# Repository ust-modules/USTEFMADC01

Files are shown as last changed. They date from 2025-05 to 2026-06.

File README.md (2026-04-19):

# EFMADC01 - Electric Field Mill ADC Module

The **EFMADC01** module is designed to provide an **analog front-end** and **ADC conversion** for [Electric Field Mill sensor](https://github.com/UniversalScientificTechnologies/THUNDERMILL01) development and experiments. It processes analog signals from the field mill electrodes and converts them into digital data for further processing.

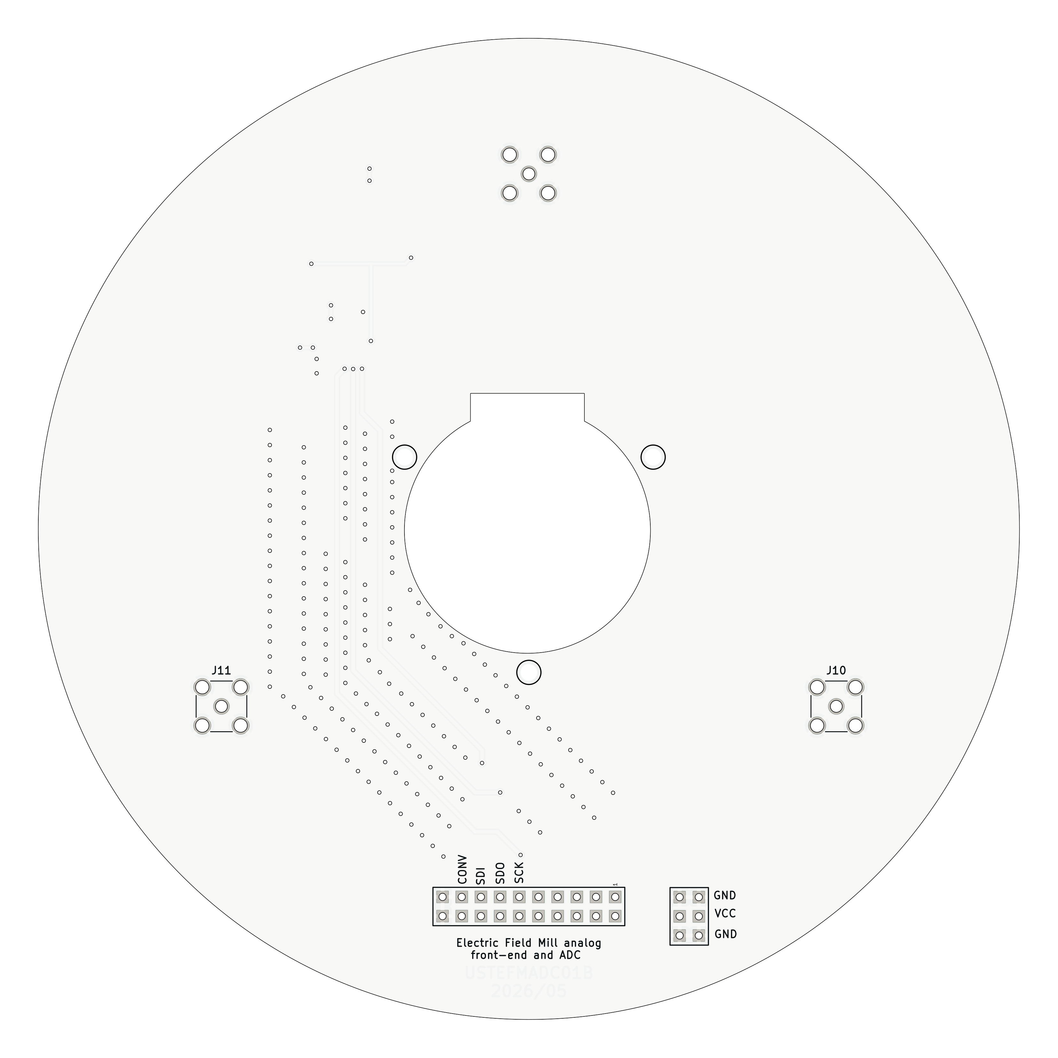
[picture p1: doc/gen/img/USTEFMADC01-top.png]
EFMADC01 top


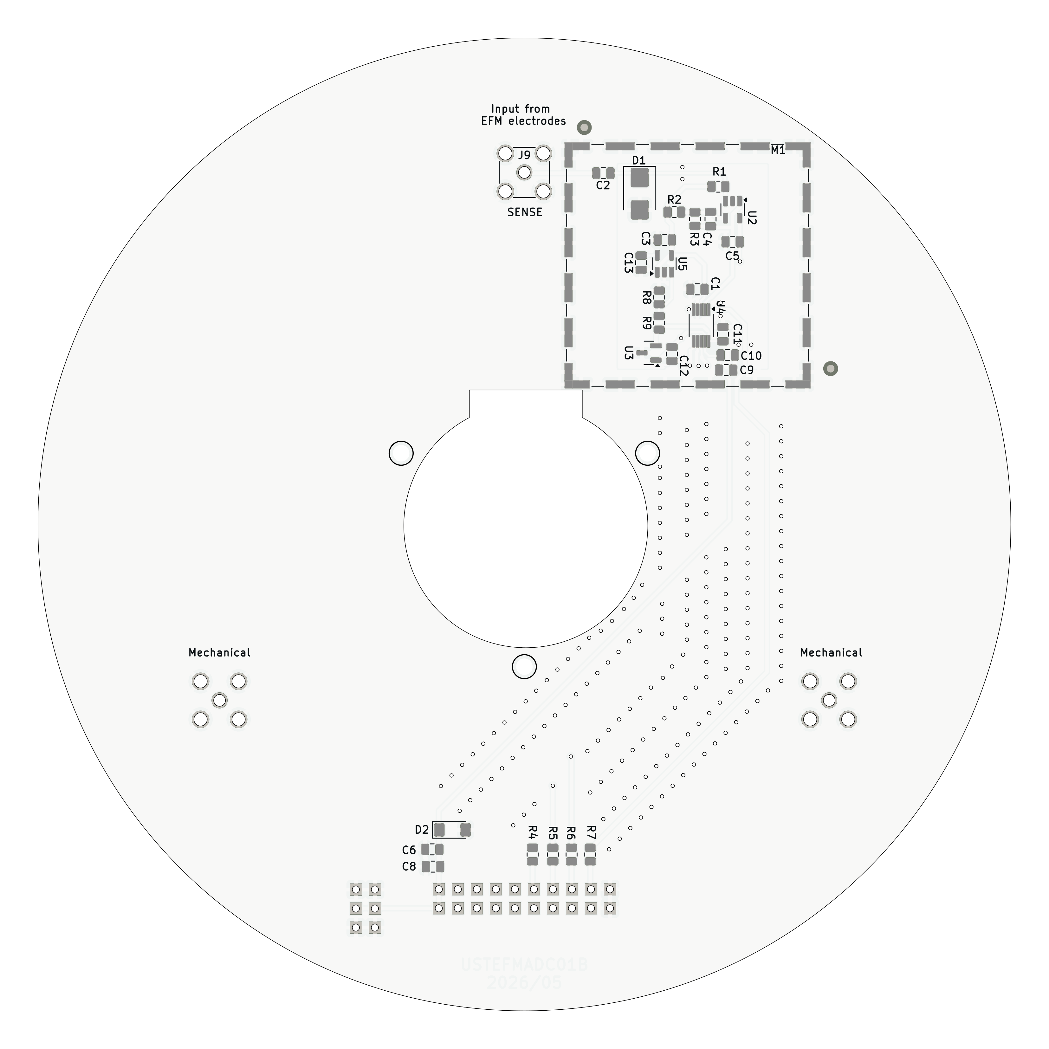
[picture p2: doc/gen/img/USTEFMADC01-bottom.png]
EFMADC01 bottom


## Features

- **High-Precision ADC**: Utilizes the **LTC1865** 16-bit, 250ksps analog-to-digital converter.
- **Low-Noise Analog Front End**: Incorporates **OPA314** operational amplifiers for signal conditioning.
- **Precision and stable Voltage Reference**: Includes a **1.25V reference** for accurate ADC operation.
- **Flexible Power Supply**: Supports **3.3V to 5V** operation.
- **RF Shielding**: Equipped with shielding to reduce external interference.
- **MCX Connector Input**: Enables high-quality signal connection.

## Functional Description

The **EFMADC01** module consists of three main blocks:

1. **Analog Front End (AFE)**:
   - Uses **OPA314** operational amplifiers for signal buffering and amplification.
   - High-impedance resistor (10MΩ) allows direct signal acquisition from the field mill sensor electrodes.

2. **ADC Conversion**:
   - **LTC1865-MS** ADC provides **16-bit resolution** with **250ksps sampling rate**.
   - Accepts differential input signals and supports SPI communication.

3. **Power and Reference**:
   - Powered by an external **3.3V or 5V** supply.
   - Features a **BZV55C-6.2V** Zener diode for overvoltage protection.
   - Uses a **1.25V precision voltage reference** for ADC stability.

## Hardware Connections

### Power Supply:
- **VCC**: Accepts **3.3V to 5V** input.
- **GNDA** and **GND**: Ground connections.

### Analog Input:
- **J9 (MCX Connector)**: Main analog signal input.
- **Operational amplifier stage** conditions the signal before ADC conversion.

## Typical Application

The **EFMADC01** module is primarily used in electric field mill experiments to measure atmospheric electric fields. It can also be employed in low-frequency scientific measurements where high-resolution ADC conversion is required.

## Schematic

For detailed circuit information, please take a look at the [EFMADC01 schematic](/doc/gen/EFMADC01-schematic.pdf) in the documentation.

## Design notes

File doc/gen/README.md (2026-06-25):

# PCB

Board size: 130.0x130.0 mm (5.12x5.12 inches)

- This is the size of the rectangle that contains the board
- Thickness: 1.6 mm (63 mils)
- Material: FR4
- Finish: Immersion gold
- Layers: 2
- Copper thickness: 35 µm

Solder mask: TOP / BOTTOM

- Color: White

Silk screen: TOP / BOTTOM

- Color: Black

Special features:

- Edge plating

Stackup:

| Name | Type | Color | Thickness [µm]| Material | Er | Loss tan |
|---|---|---|---|---|---|---|
| F.SilkS | Top Silk Screen | Black | | | | |
| F.Paste | Top Solder Paste | | | | | |
| F.Mask | Top Solder Mask | White | 10 | | | |
| F.Cu | copper | | 35 | | | |
| dielectric 1 | core | | 1510 | FR4 | 4.5 | 0.020 |
| B.Cu | copper | | 35 | | | |
| B.Mask | Bottom Solder Mask | White | 10 | | | |
| B.Paste | Bottom Solder Paste  | | | | | |
| B.SilkS | Bottom Silk Screen | Black | | | | |

# Important sizes

Clearance: 0.2 mm (8 mils)

Track width: 0.2 mm (8 mils)

- By design rules: 0.2 mm (8 mils)

Drill: 0.5 mm (20 mils)

- Vias: 0.5 mm (20 mils) [Design: 0.4 mm (16 mils)]
- Pads: 1.0 mm (39 mils)
- The above values are real drill sizes, they add 0.1 mm (4 mils) to plated holes (PTH)

Via: 0.8/0.4 mm (31/16 mils)

- By design rules: 0.4/0.3 mm (16/12 mils)
- Micro via: yes [0.2/0.1 mm (8/4 mils)]
- Buried/blind via: yes
- Total: 195 (thru: 195 buried/blind: 0 micro: 0)

Outer Annular Ring: 0.15 mm (6 mils)

- By design rules: 0.23 mm (9 mils)

Eurocircuits class: 4B
- Using min drill 0.5 mm for an OAR of 0.15 mm

# General stats

Components count: (SMD/THT)

- Top: 0/4 (THT)
- Bottom: 30/2 (SMD + THT)

Defined tracks:

- 0.2 mm (8 mils)
- 0.25 mm (10 mils)
- 0.3 mm (12 mils)
- 0.45 mm (18 mils)
- 0.5 mm (20 mils)

Used tracks:

- 0.2 mm (8 mils) (5) defined: yes
- 0.25 mm (10 mils) (24) defined: yes
- 0.3 mm (12 mils) (25) defined: yes
- 0.45 mm (18 mils) (92) defined: yes

Defined vias:

Used vias:

- 0.8/0.4 mm (31/16 mils) (Count: 195, Aspect: 2.0 A) defined: no

Holes (excluding vias):

- 0.89 mm (35 mils) (26)
- 1.5 mm (59 mils) (3)
- 1.7 mm (67 mils) (12)

Oval holes:

Drill tools (including vias and computing adjusts and rounding):

- 0.5 mm (20 mils) (195)
- 1.0 mm (39 mils) (26)
- 1.6 mm (63 mils) (3)
- 1.8 mm (71 mils) (12)

Solder paste stats:

Using a paste with 87.75 % alloy, that has an specific gravity for the alloy of 7.4 g/cm³
and 1.0 g/cm³ for the flux. This paste has an specific gravity of  4.15 g/cm³.

The stencil thickness is  0.12 mm.

| Side | Pads with paste | Area [mm²] | Paste [g] |
|---|---|---|---|
| Total  | 97 | 173.00 | 0.86 |

Note: this is just an approximation to the theoretical value. Margins of the solder mask and waste aren't computed.

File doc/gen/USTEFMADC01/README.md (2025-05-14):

# PCB

Board size: 130.0x130.0 mm (5.12x5.12 inches)

- This is the size of the rectangle that contains the board
- Thickness: 1.6 mm (63 mils)
- Material: FR4
- Finish: Immersion gold
- Layers: 2
- Copper thickness: 35 µm

Solder mask: TOP / BOTTOM

- Color: White

Silk screen: TOP / BOTTOM

- Color: Black

Special features:

- Castellated pads
- Edge plating

Stackup:

| Name | Type | Color | Thickness [µm]| Material | Er | Loss tan |
|---|---|---|---|---|---|---|
| F.SilkS | Top Silk Screen | Black | | | | |
| F.Paste | Top Solder Paste | | | | | |
| F.Mask | Top Solder Mask | White | 10 | | | |
| F.Cu | copper | | 35 | | | |
| dielectric 1 | core | | 1510 | FR4 | 4.5 | 0.020 |
| B.Cu | copper | | 35 | | | |
| B.Mask | Bottom Solder Mask | White | 10 | | | |
| B.Paste | Bottom Solder Paste  | | | | | |
| B.SilkS | Bottom Silk Screen | Black | | | | |

# Important sizes

Clearance: 0.2 mm (8 mils)

Track width: 0.2 mm (8 mils)

- By design rules: 0.2 mm (8 mils)

Drill: 0.5 mm (20 mils)

- Vias: 0.5 mm (20 mils) [Design: 0.4 mm (16 mils)]
- Pads: 1.0 mm (39 mils)
- The above values are real drill sizes, they add 0.1 mm (4 mils) to plated holes (PTH)

Via: 0.8/0.4 mm (31/16 mils)

- By design rules: 0.4/0.3 mm (16/12 mils)
- Micro via: yes [0.2/0.1 mm (8/4 mils)]
- Buried/blind via: yes
- Total: 195 (thru: 195 buried/blind: 0 micro: 0)

Outer Annular Ring: 0.15 mm (6 mils)

- By design rules: 0.23 mm (9 mils)

Eurocircuits class: 4B
- Using min drill 0.5 mm for an OAR of 0.15 mm

# General stats

Components count: (SMD/THT)

- Top: 0/2 (THT)
- Bottom: 30/1 (SMD + THT)

Defined tracks:

- 0.2 mm (8 mils)
- 0.25 mm (10 mils)
- 0.3 mm (12 mils)
- 0.45 mm (18 mils)
- 0.5 mm (20 mils)

Used tracks:

- 0.2 mm (8 mils) (5) defined: yes
- 0.25 mm (10 mils) (24) defined: yes
- 0.3 mm (12 mils) (25) defined: yes
- 0.45 mm (18 mils) (91) defined: yes

Defined vias:

Used vias:

- 0.8/0.4 mm (31/16 mils) (Count: 195, Aspect: 2.0 A) defined: no

Holes (excluding vias):

- 0.89 mm (35 mils) (26)
- 1.5 mm (59 mils) (1)
- 1.7 mm (67 mils) (4)

Oval holes:

Drill tools (including vias and computing adjusts and rounding):

- 0.5 mm (20 mils) (195)
- 1.0 mm (39 mils) (26)
- 1.6 mm (63 mils) (1)
- 1.8 mm (71 mils) (4)

Solder paste stats:

Using a paste with 87.75 % alloy, that has an specific gravity for the alloy of 7.4 g/cm³
and 1.0 g/cm³ for the flux. This paste has an specific gravity of  4.15 g/cm³.

The stencil thickness is  0.12 mm.

| Side | Pads with paste | Area [mm²] | Paste [g] |
|---|---|---|---|
| Total  | 97 | 173.00 | 0.86 |

Note: this is just an approximation to the theoretical value. Margins of the solder mask and waste aren't computed.

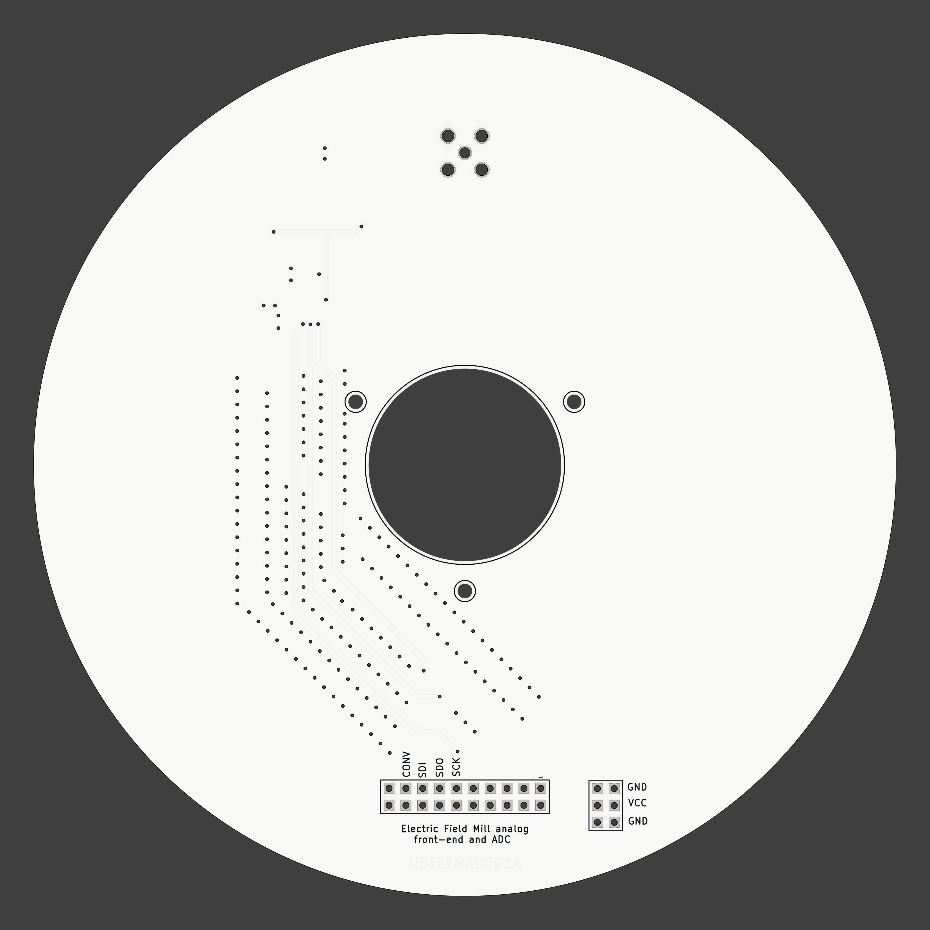
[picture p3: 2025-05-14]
doc/gen/USTEFMADC01/img/USTEFMADC01-top.png

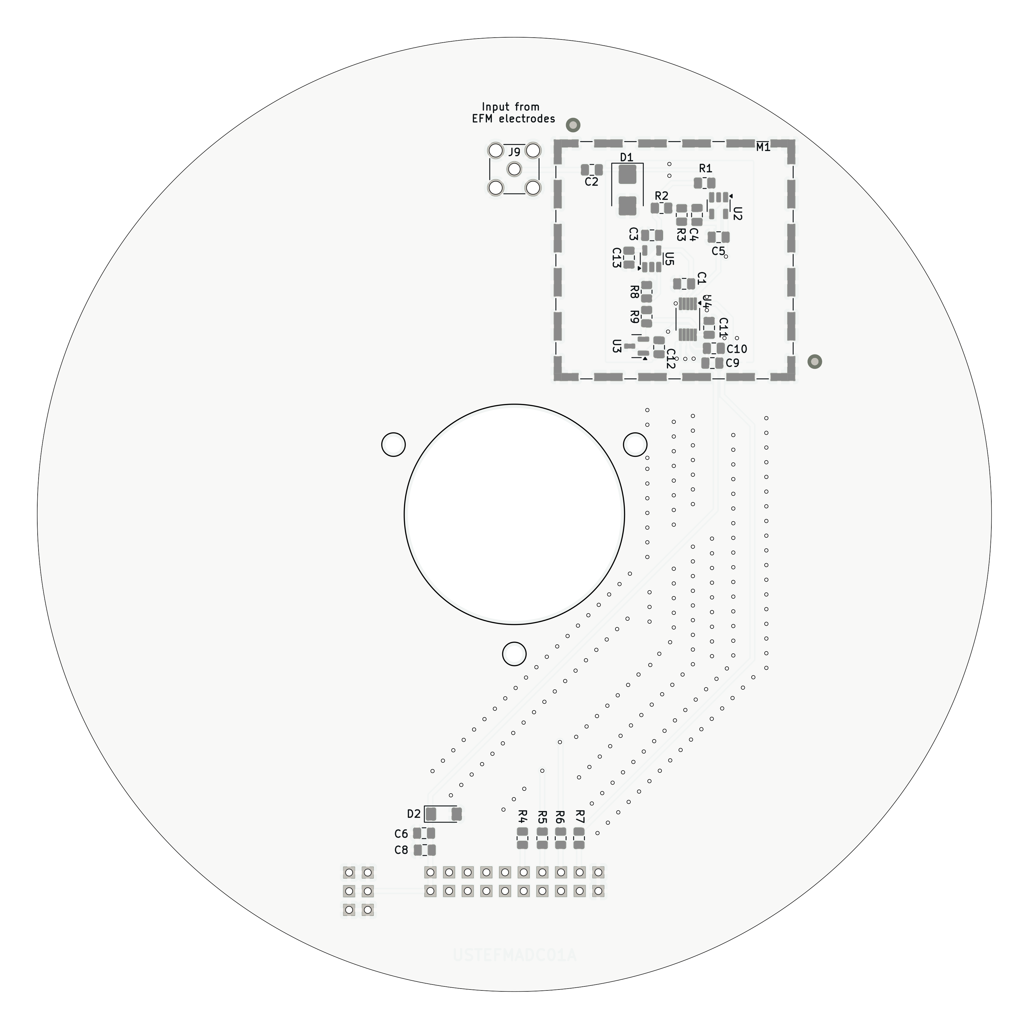
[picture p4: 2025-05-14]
doc/gen/USTEFMADC01/img/USTEFMADC01-bottom.png

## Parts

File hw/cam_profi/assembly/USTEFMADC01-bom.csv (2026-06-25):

Component | Description | Part | References | Value | Footprint | Quantity Per PCB | Datasheet | ust_id
1 | Unpolarized capacitor | C | C2C4 | 10nF | C_0805_2012Metric | 2 |  | 6508260b462c6d9e720541f1 5c70984812875079b91f8ba6
2 | Unpolarized capacitor | C | C1C3C5C6C10C11C12C13 | 100nF | C_0805_2012Metric | 8 |  | 6508260b462c6d9e720541f1 5c70984712875079b91f8b4c
3 | Unpolarized capacitor | C | C8C9 | 10uF | C_0805_2012Metric | 2 |  | 5c70984812875079b91f8bbe
4 | Zener diode | D_Zener | D2 | BZV55C-6,2V | D_MiniMELF | 1 |  | 604b0326128750769e5b0f93
5 | 600W unidirectional Transil Transient Voltage Suppressor, 12Vrwm, DO-214AA | SM6T12A | D1 | UCLAMP3301H.TCT | D_SMB | 1 | https://www.st.com/resource/en/datasheet/sm6t.pdf | 612514fe1287500165a976f3
6 | 2x10 2.54 mm pitch header | HEADER_2x10 | J1001 | HEADER_2x10 | Straight_2x10 | 1
7 | coaxial connector (BNC, SMA, SMB, SMC, Cinch/RCA, LEMO, ...) | Conn_Coaxial | J9J10J11 | MCX | SMA_Amphenol_901-144_Vertical | 3 |  | 5fa10cc512875025b39779f6
8 | Two-piece EMI RF shielding cabinet | RFShield_TwoPieces | M1 | RFShield_TwoPieces | Laird_Technologies_BMI-S-204-F_32.00x32.00mm | 1 |  | 5c72751c1287500b4e11301a
9 | Resistor | R | R4R5R6R7 | 33R | R_0805_2012Metric | 4 |  | 5c70984512875079b91f8970
10 | Resistor | R | R8R9 | 1k | R_0805_2012Metric | 2 |  | 5c70984712875079b91f8b6d
11 | Resistor | R | R2 | 3k3 | R_0805_2012Metric | 1 |  | 5c70984512875079b91f895e
12 | Resistor | R | R3 | 33k | R_0805_2012Metric | 1 |  | 5c70984512875079b91f8962
13 | Resistor | R | R1 | 270k | R_0805_2012Metric | 1 |  | 5c70984712875079b91f8b6d
14 | 2.0V 25μA Micropower Voltage Reference, SOT-23 | ISL21070CIH320Z-TK | U3 | ISL21080CIH330Z-TK | SOT-23 | 1 | http://www.intersil.com/content/dam/Intersil/documents/fn75/fn7599.pdf | 67d36d64ee7fc534862c3ebc
15 | Dual channel 16-bit SAR Analog to Digital Converter, 5V supply, 150ksps, SPI interface | LTC1865-MS | U4 | LTC1865-MS | MSOP-10_3x3mm_P0.5mm | 1 | https://www.analog.com/media/en/technical-documentation/data-sheets/18645fb.pdf | 651eae84462c6d9e7205573b
16 | 50μV V OS, 0.25μV/°C, 35μA CMOS OPERATIONAL AMPLIFIERS, Zerø-Drift Series, SOT | OPA330xxDBV | U2U5 | OPA314 | SOT-23-5 | 2 | http://www.ti.com/lit/ds/symlink/opa330.pdf | 5c70984412875079b91f879a

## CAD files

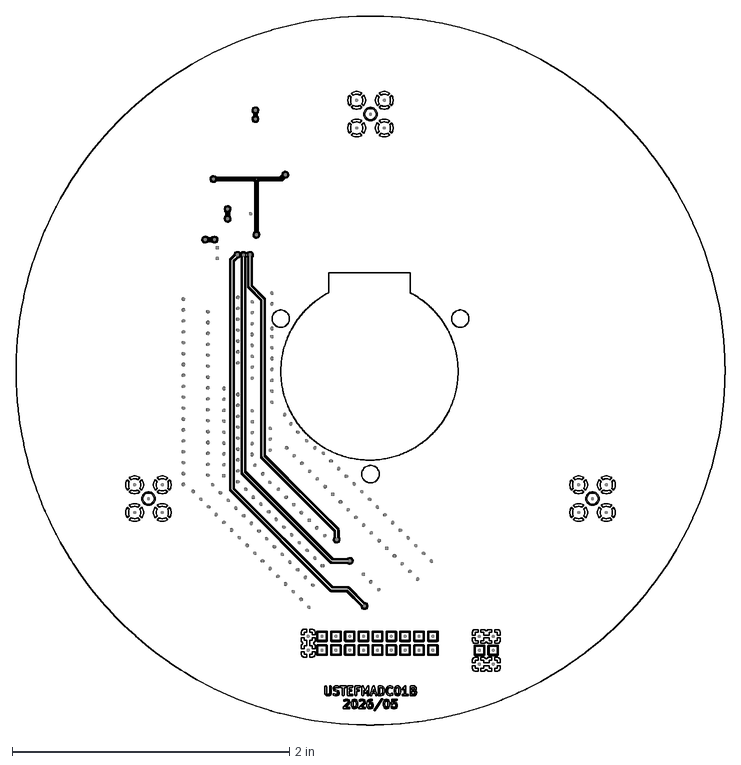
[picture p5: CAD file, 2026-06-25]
doc/gen/dxf/USTEFMADC01-F_Cu.dxf
5.12 x 5.12 in

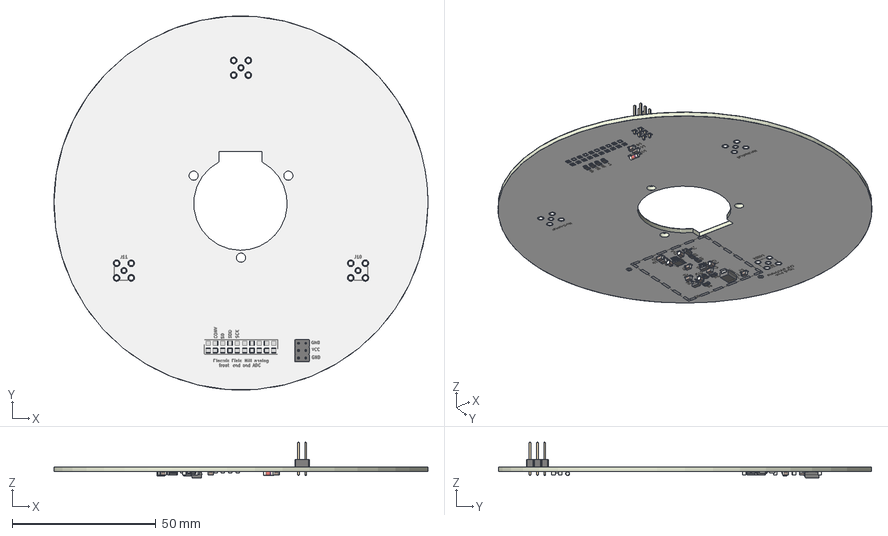
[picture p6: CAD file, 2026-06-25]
doc/gen/mesh/USTEFMADC01.step
130.0 x 130.0 x 12.4 mm
PinHeader_2x03_P2.54mm_Vertical
R_0805_2012Metric x 9
SOT-23
C_0805_2012Metric x 12
SOT-23-5 x 2
D_MiniMELF
MSOP-10_3x3mm_P0.5mm
D_SMB
kibot_ig_w9ij7_copper
kibot_ig_w9ij7_pad
kibot_ig_w9ij7_via
kibot_ig_w9ij7_silkscreen x 2
kibot_ig_w9ij7_soldermask x 2
kibot_ig_w9ij7_PCB

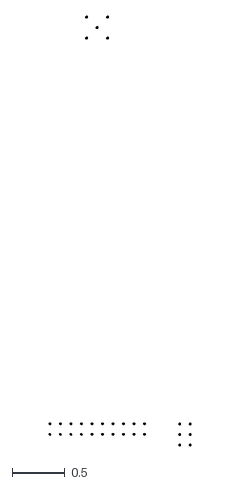
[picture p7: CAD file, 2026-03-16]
doc/gen/USTEFMADC01/dxf/USTEFMADC01-F_Courtyard.dxf
1.35 x 4.08

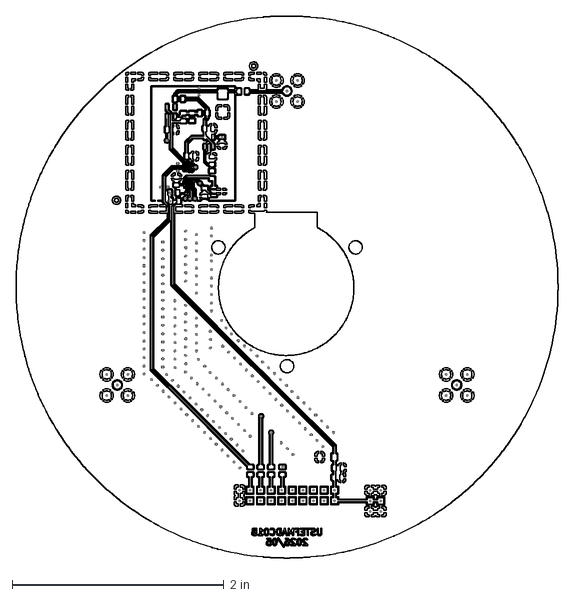
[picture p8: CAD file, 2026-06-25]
doc/gen/dxf/USTEFMADC01-B_Cu.dxf
5.12 x 5.12 in

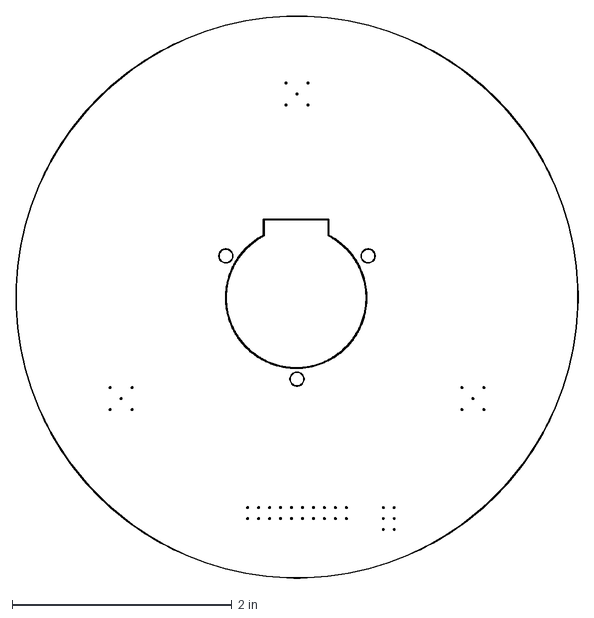
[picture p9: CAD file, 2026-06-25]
doc/gen/dxf/USTEFMADC01-Edge_Cuts.dxf
5.12 x 5.12 in

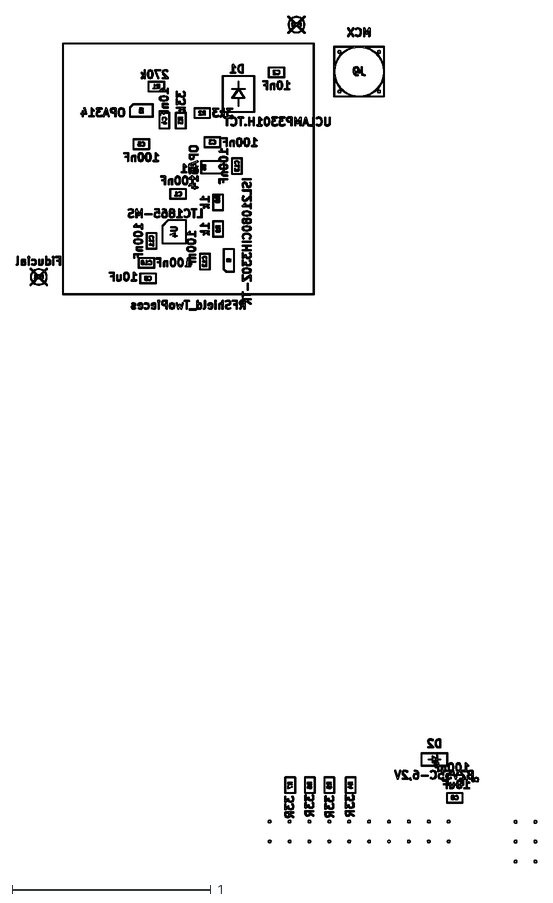
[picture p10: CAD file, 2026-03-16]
doc/gen/USTEFMADC01/dxf/USTEFMADC01-B_Fab.dxf
2.62 x 4.26

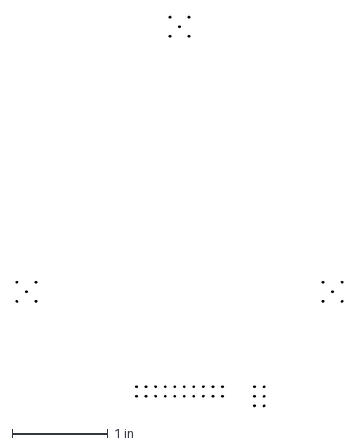
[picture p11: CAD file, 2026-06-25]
doc/gen/dxf/USTEFMADC01-User_Comments.dxf
3.42 x 4.08 in

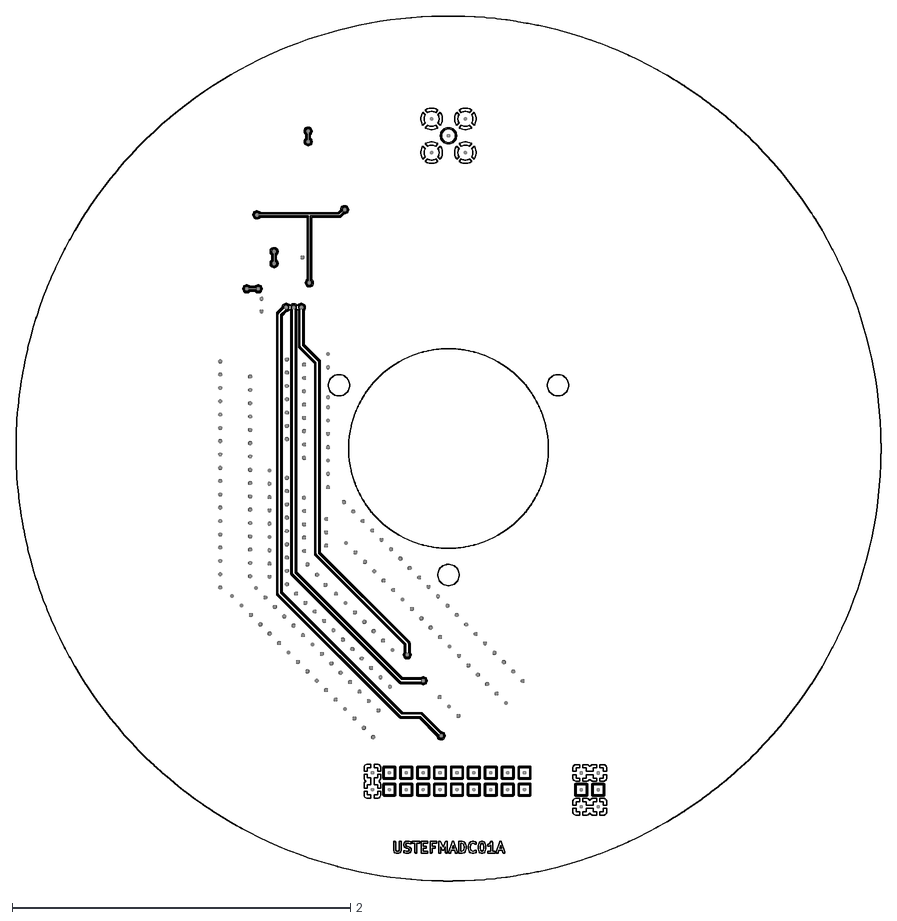
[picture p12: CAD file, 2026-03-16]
doc/gen/USTEFMADC01/dxf/USTEFMADC01-F_Cu.dxf
5.12 x 5.12

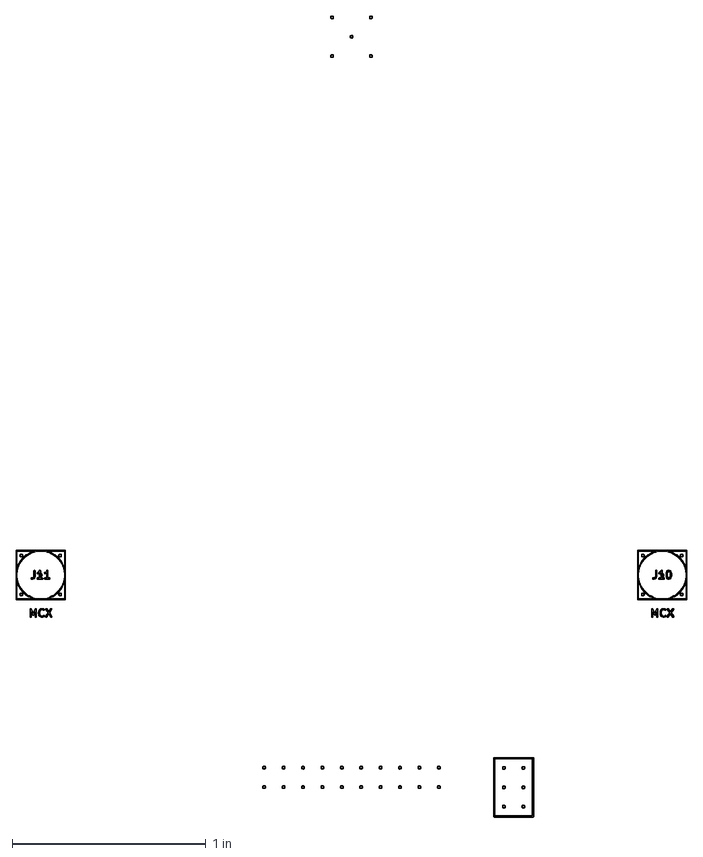
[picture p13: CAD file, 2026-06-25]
doc/gen/dxf/USTEFMADC01-F_Fab.dxf
3.46 x 4.13 in

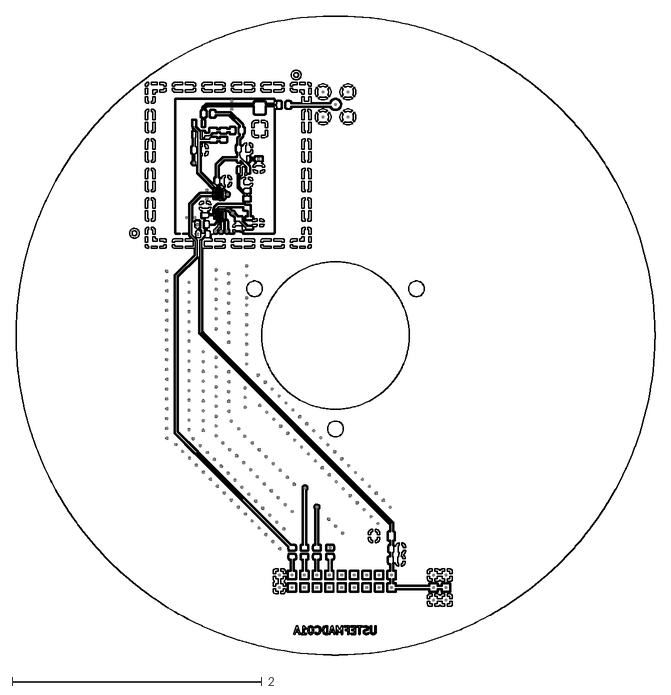
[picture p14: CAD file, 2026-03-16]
doc/gen/USTEFMADC01/dxf/USTEFMADC01-B_Cu.dxf
5.12 x 5.12

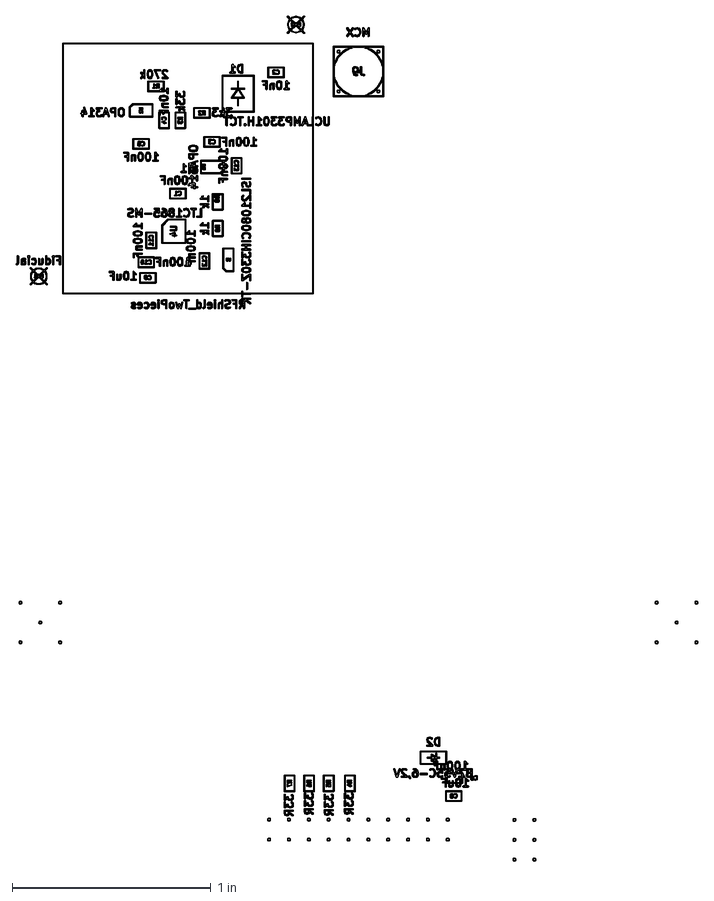
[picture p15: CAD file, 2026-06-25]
doc/gen/dxf/USTEFMADC01-B_Fab.dxf
3.43 x 4.26 in

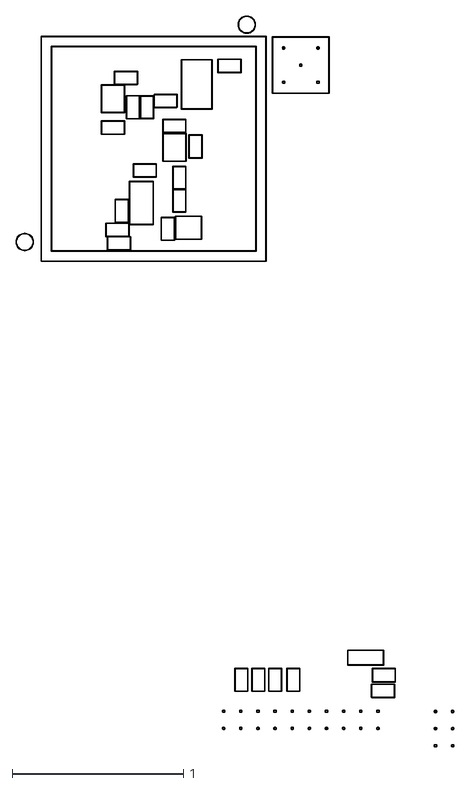
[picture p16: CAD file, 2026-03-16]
doc/gen/USTEFMADC01/dxf/USTEFMADC01-B_Courtyard.dxf
2.55 x 4.26

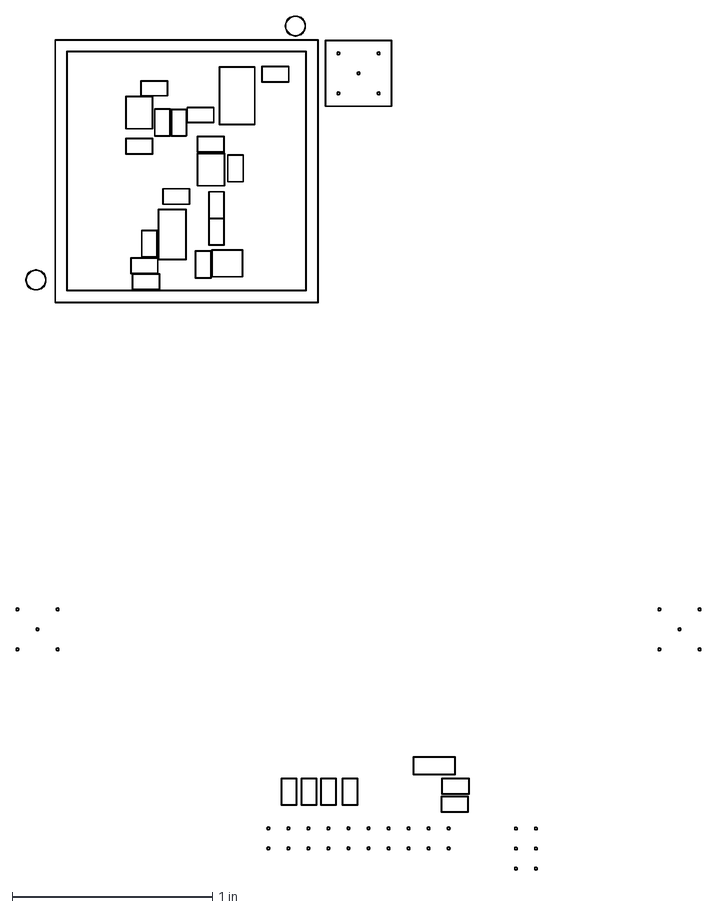
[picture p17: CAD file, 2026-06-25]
doc/gen/dxf/USTEFMADC01-B_Courtyard.dxf
3.42 x 4.26 in

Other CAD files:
doc/gen/USTEFMADC01/mesh/USTEFMADC01.step
doc/gen/USTEFMADC01/dxf/USTEFMADC01-B_Adhesive.dxf
doc/gen/USTEFMADC01/dxf/USTEFMADC01-B_Mask.dxf
doc/gen/USTEFMADC01/dxf/USTEFMADC01-B_Paste.dxf
doc/gen/USTEFMADC01/dxf/USTEFMADC01-B_Silkscreen.dxf
doc/gen/USTEFMADC01/dxf/USTEFMADC01-Edge_All.dxf
doc/gen/USTEFMADC01/dxf/USTEFMADC01-Edge_Cuts.dxf
doc/gen/USTEFMADC01/dxf/USTEFMADC01-F_Adhesive.dxf
doc/gen/USTEFMADC01/dxf/USTEFMADC01-F_Fab.dxf
doc/gen/USTEFMADC01/dxf/USTEFMADC01-F_Mask.dxf
doc/gen/USTEFMADC01/dxf/USTEFMADC01-F_Paste.dxf
doc/gen/USTEFMADC01/dxf/USTEFMADC01-F_Silkscreen.dxf
doc/gen/dxf/USTEFMADC01-B_Adhesive.dxf
doc/gen/dxf/USTEFMADC01-B_Mask.dxf
doc/gen/dxf/USTEFMADC01-B_Paste.dxf
doc/gen/dxf/USTEFMADC01-B_Silkscreen.dxf
doc/gen/dxf/USTEFMADC01-F_Adhesive.dxf
doc/gen/dxf/USTEFMADC01-F_Courtyard.dxf
doc/gen/dxf/USTEFMADC01-F_Mask.dxf
doc/gen/dxf/USTEFMADC01-F_Paste.dxf
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

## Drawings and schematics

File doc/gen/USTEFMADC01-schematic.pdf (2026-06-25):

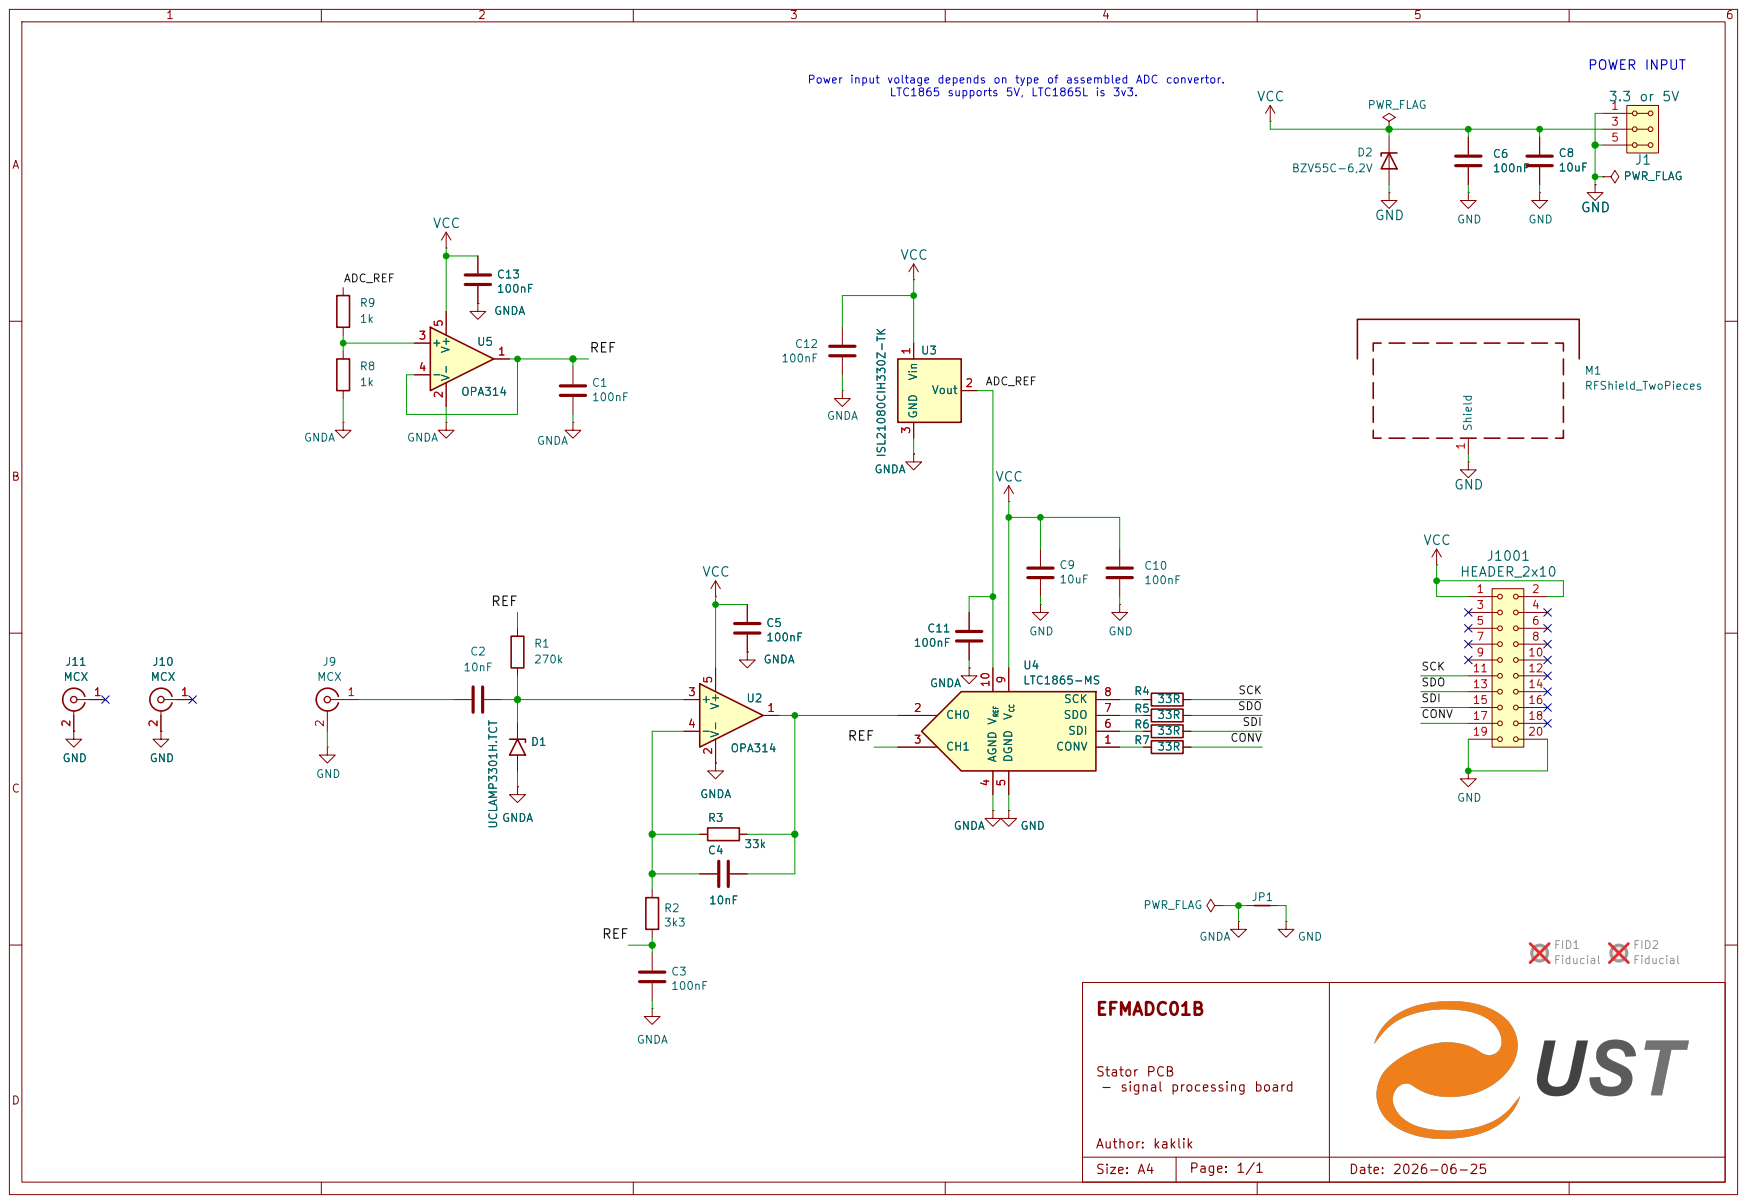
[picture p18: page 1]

EFMADC01B Stator PCB - signal processing board Author: kaklik

Size: A4 | Page: 1/1 | Date: 2026-06-25

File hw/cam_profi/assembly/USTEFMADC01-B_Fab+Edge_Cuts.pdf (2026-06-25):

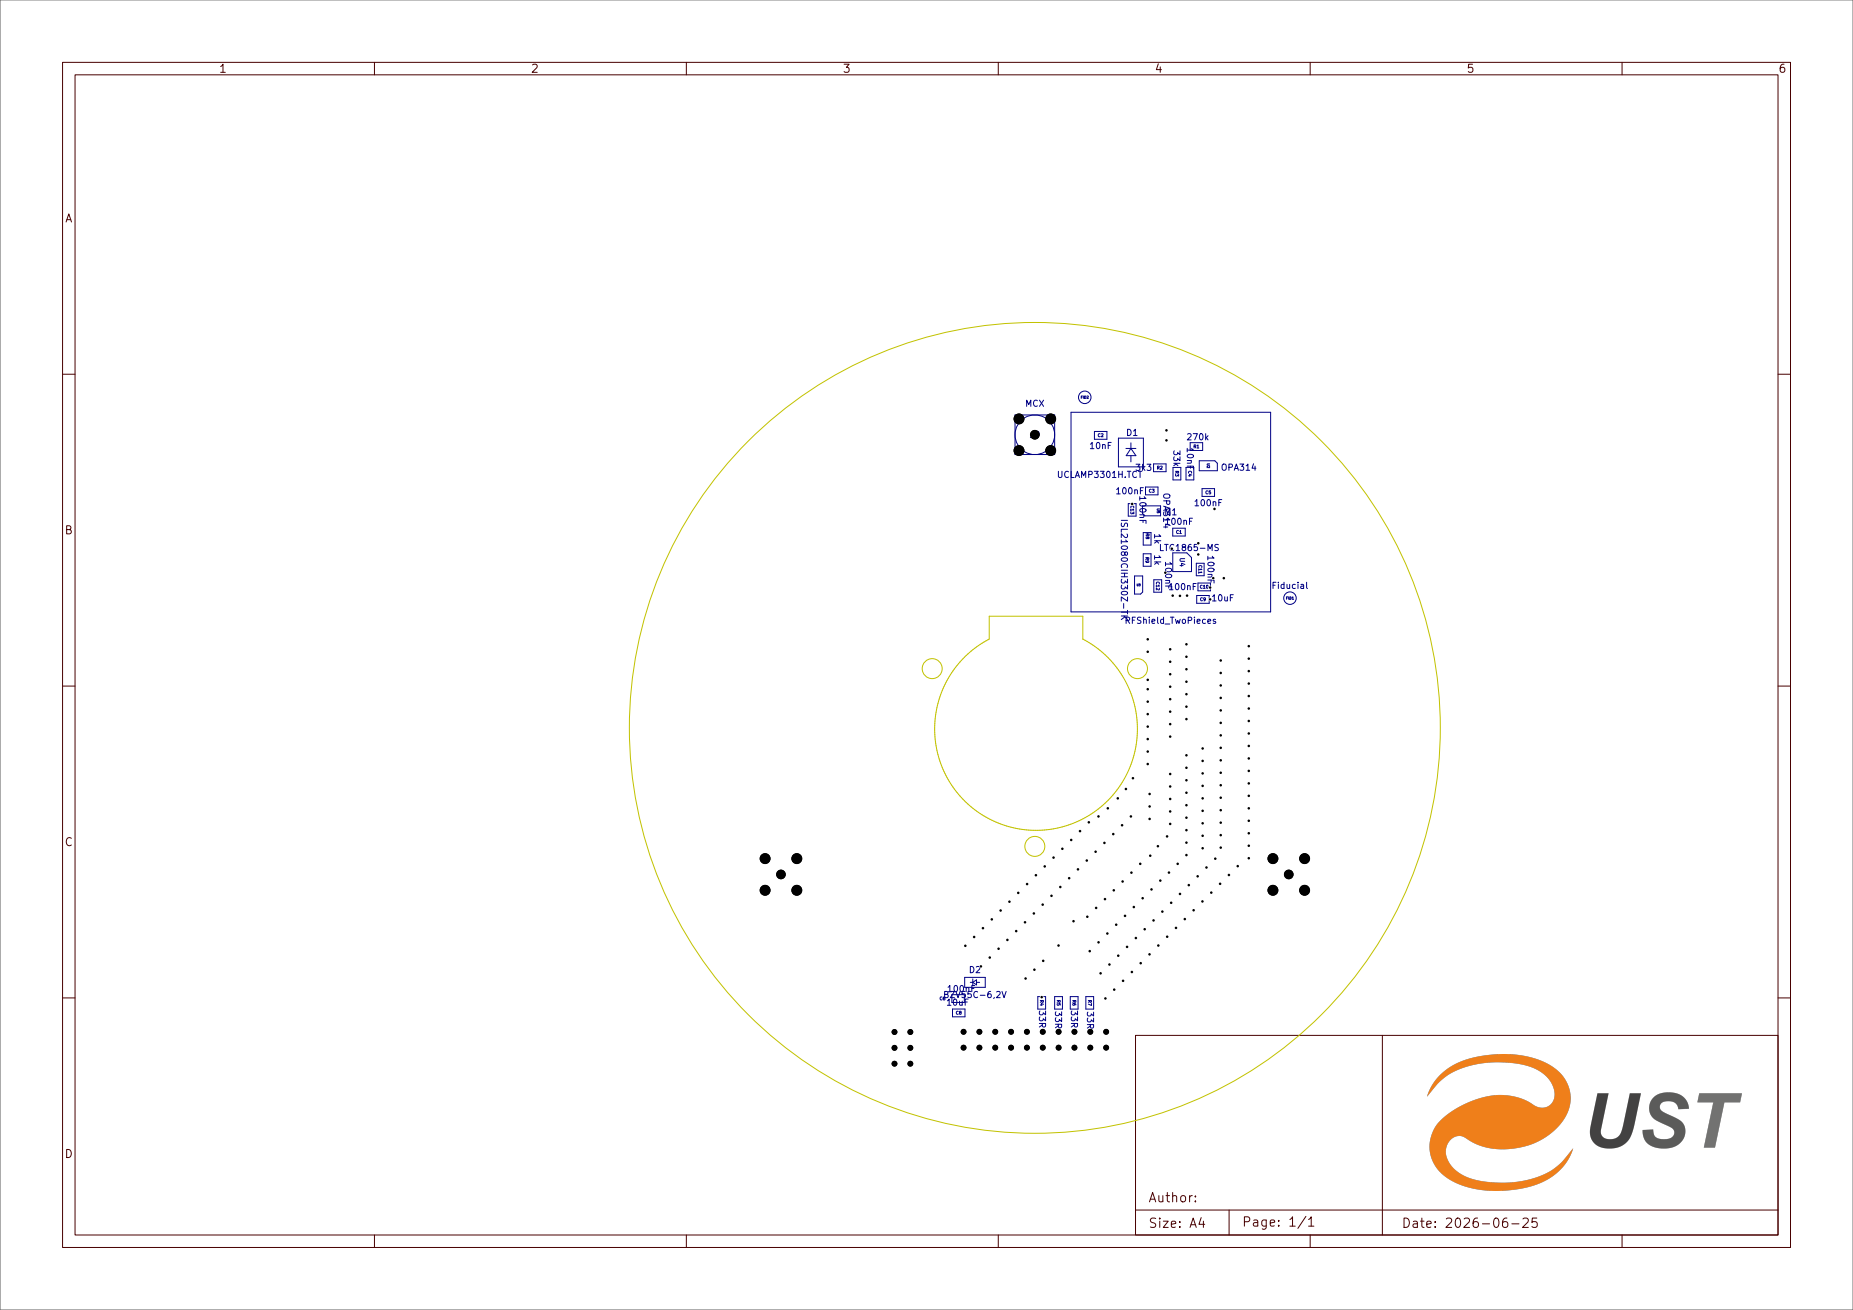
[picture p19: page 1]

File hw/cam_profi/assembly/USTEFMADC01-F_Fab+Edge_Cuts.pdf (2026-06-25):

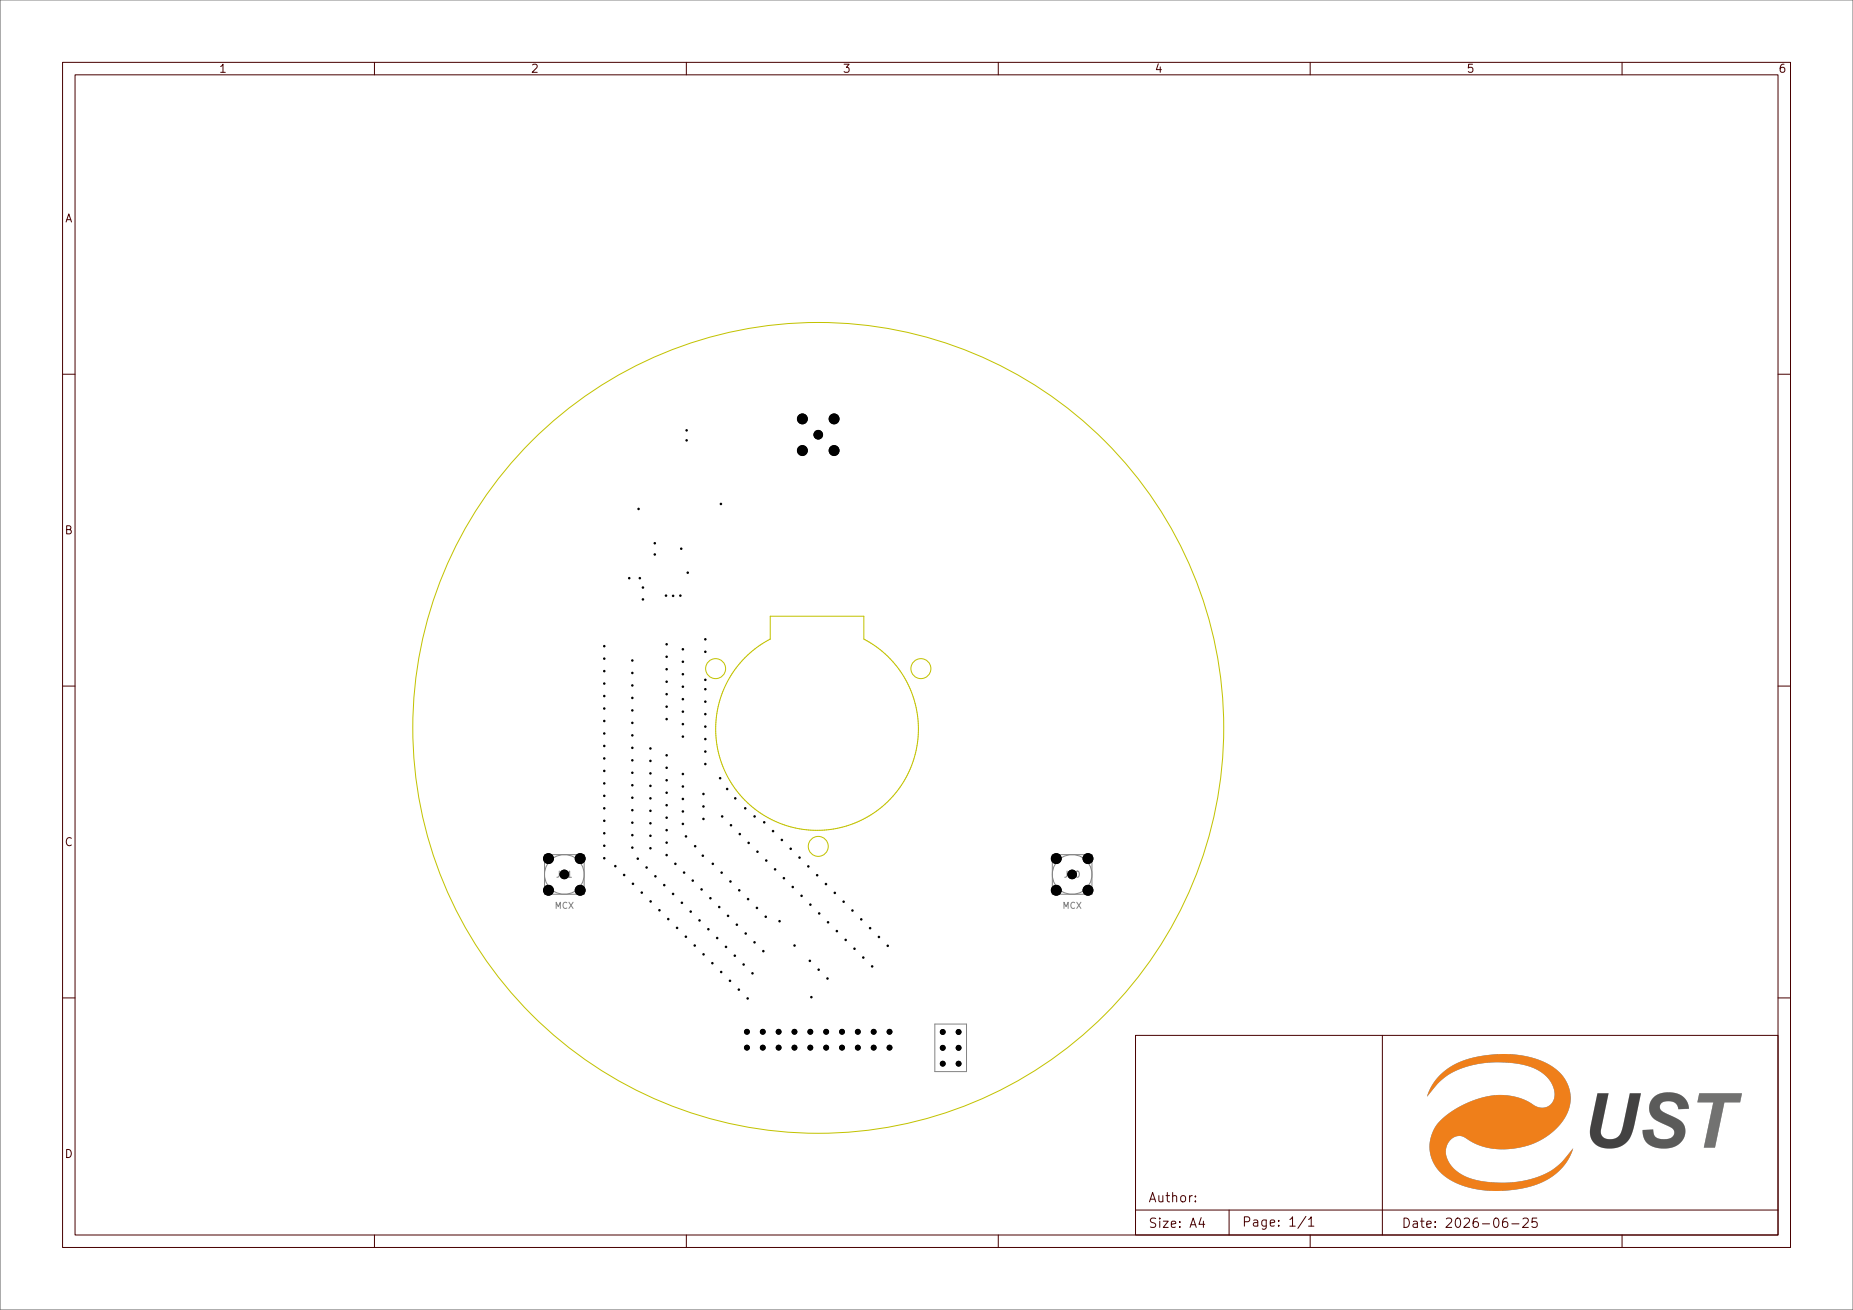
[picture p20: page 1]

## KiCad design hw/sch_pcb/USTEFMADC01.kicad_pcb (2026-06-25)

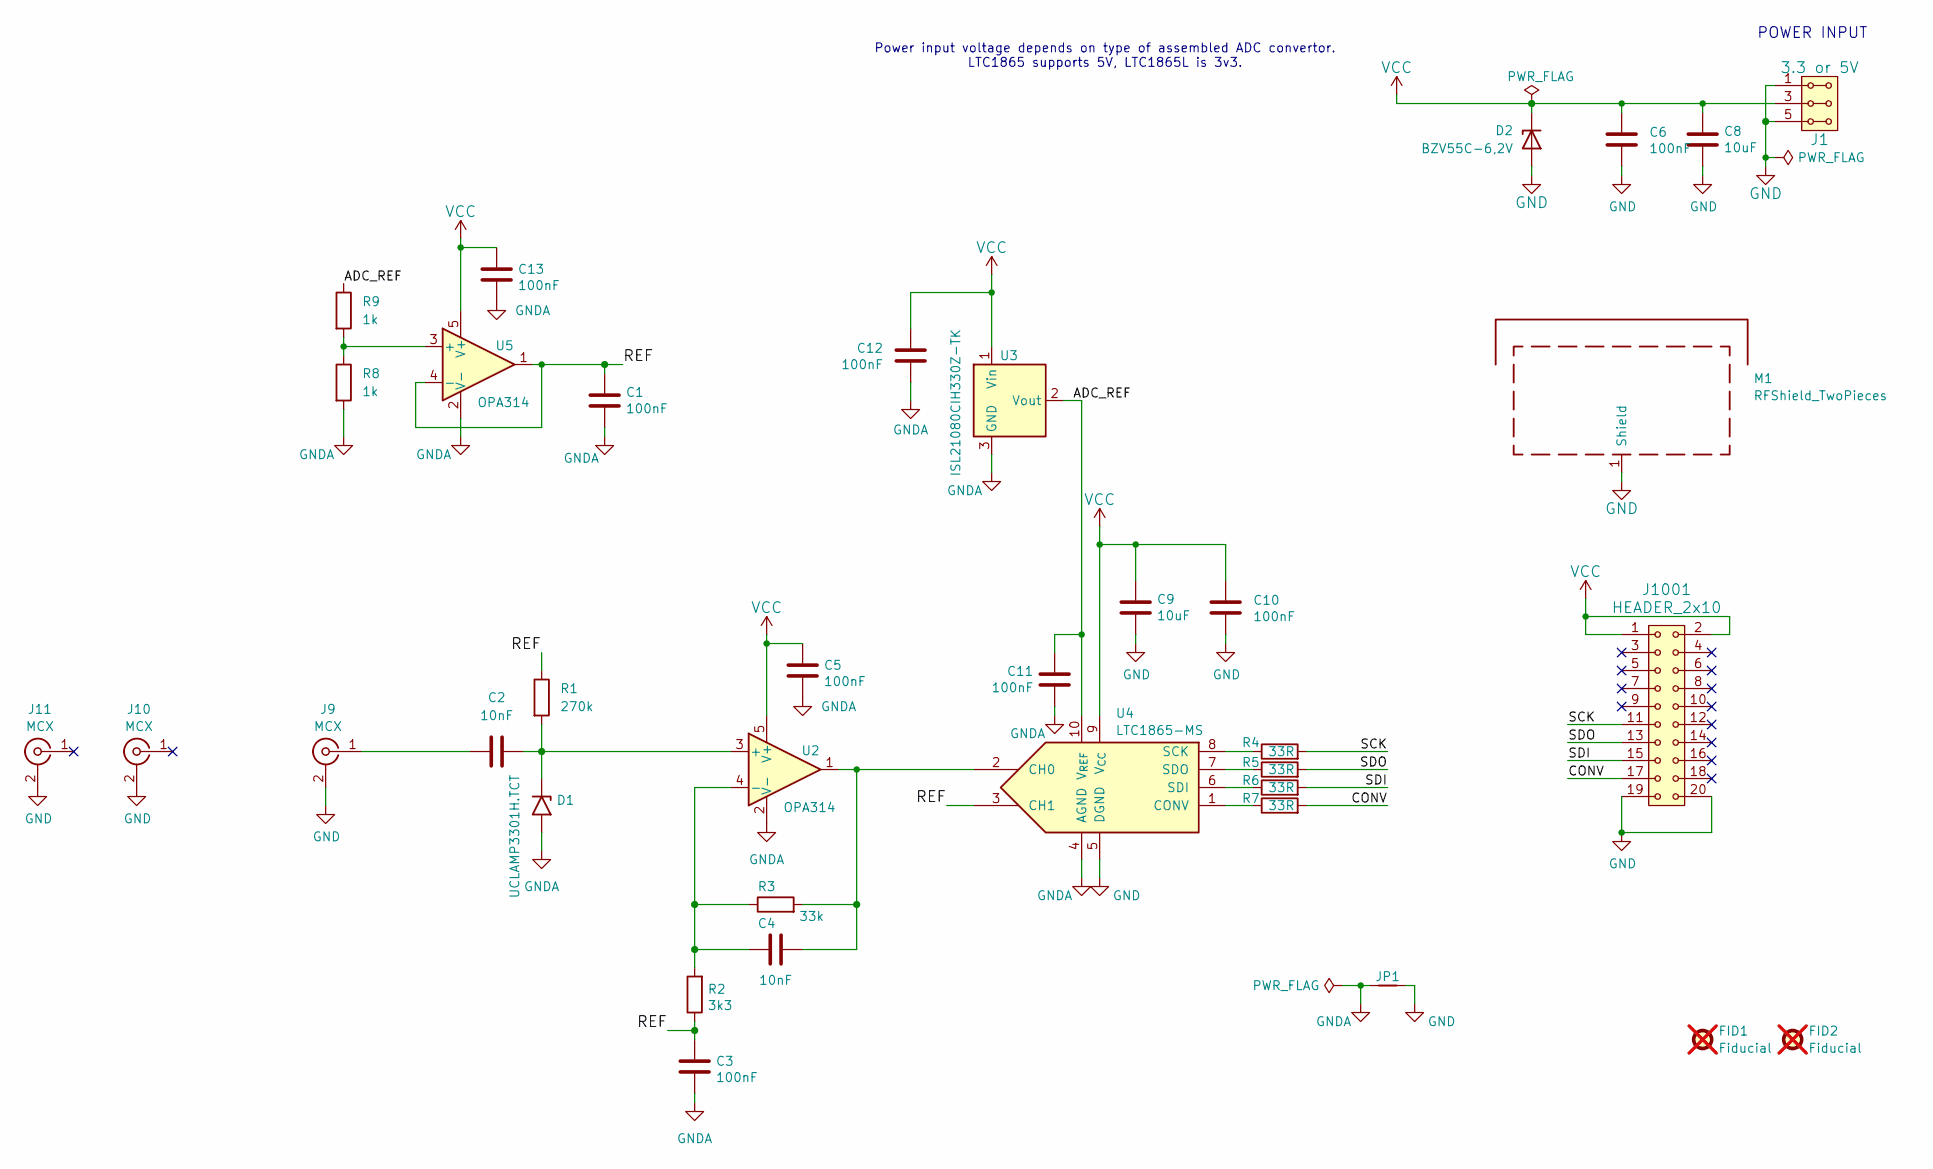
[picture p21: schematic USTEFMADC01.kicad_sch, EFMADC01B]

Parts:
C1, C3, C5, C6, C10, C11, C12, C13: 100nF; C_0805_2012Metric
C2, C4: 10nF; C_0805_2012Metric
C8, C9: 10uF; C_0805_2012Metric
D1: UCLAMP3301H.TCT; D_SMB
D2: BZV55C-6,2V; D_MiniMELF
FID1, FID2: Fiducial; Fiducial_1mm_Mask2mm; not fitted
J1: 3.3 or 5V; Straight_2x03
J9, J10, J11: MCX; SMA_Amphenol_901-144_Vertical
J1001: HEADER_2x10; Straight_2x10
JP1: Jumper_2_Bridged; NetTie-2_SMD_Pad0.5mm
M1: RFShield_TwoPieces; Laird_Technologies_BMI-S-204-F_32.00x32.00mm
R1: 270k; R_0805_2012Metric
R2: 3k3; R_0805_2012Metric
R3: 33k; R_0805_2012Metric
R4, R5, R6, R7: 33R; R_0805_2012Metric
R8, R9: 1k; R_0805_2012Metric
U2, U5: OPA314; SOT-23-5
U3: ISL21080CIH330Z-TK; SOT-23
U4: LTC1865-MS; MSOP-10_3x3mm_P0.5mm

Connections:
/ADC_REF: C11.1, R9.1, U3.2 (Vout), U4.10 (V_{REF})
/CONV: J1001.17, R7.2
/REF: C1.1, C3.2, R1.1, R2.1, U4.3 (CH1), U5.1, U5.4 (-)
/SCK: J1001.11, R4.2
/SDI: J1001.15, R6.2
/SDO: J1001.13, R5.2
GND: C6.2, C8.2, C9.2, C10.2, D2.2 (A), J1.1, J1.2, J1.5, J1.6, J9.2 (Ext), J10.2 (Ext_2), J11.2 (Ext_2), J1001.19, J1001.20, JP1.2, M1.1 (Shield_1), U4.5 (DGND)
GNDA: C1.2, C3.1, C5.1, C11.2, C12.2, C13.1, D1.2 (A2), JP1.1, R8.2, U2.2 (V-), U3.3 (GND), U4.4 (AGND), U5.2 (V-)
unnamed: C2.2, D1.1 (A1), R1.2, U2.3 (+)
unnamed: C2.1, J9.1 (In)
unnamed: C4.1, R2.2, R3.1, U2.4 (-)
unnamed: C4.2, R3.2, U2.1, U4.2 (CH0)
unnamed: R7.1, U4.1 (CONV)
unnamed: R4.1, U4.8 (SCK)
unnamed: R6.1, U4.6 (SDI)
unnamed: R5.1, U4.7 (SDO)
unnamed: R8.1, R9.2, U5.3 (+)
VCC: C5.2, C6.1, C8.1, C9.1, C10.1, C12.1, C13.2, D2.1 (K), J1.3, J1.4, J1001.1, J1001.2, U2.5 (V+), U3.1 (Vin), U4.9 (V_{CC}), U5.5 (V+)

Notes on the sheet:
Power input voltage depends on type of assembled ADC convertor. LTC1865 supports 5V, LTC1865L is 3v3.
POWER INPUT

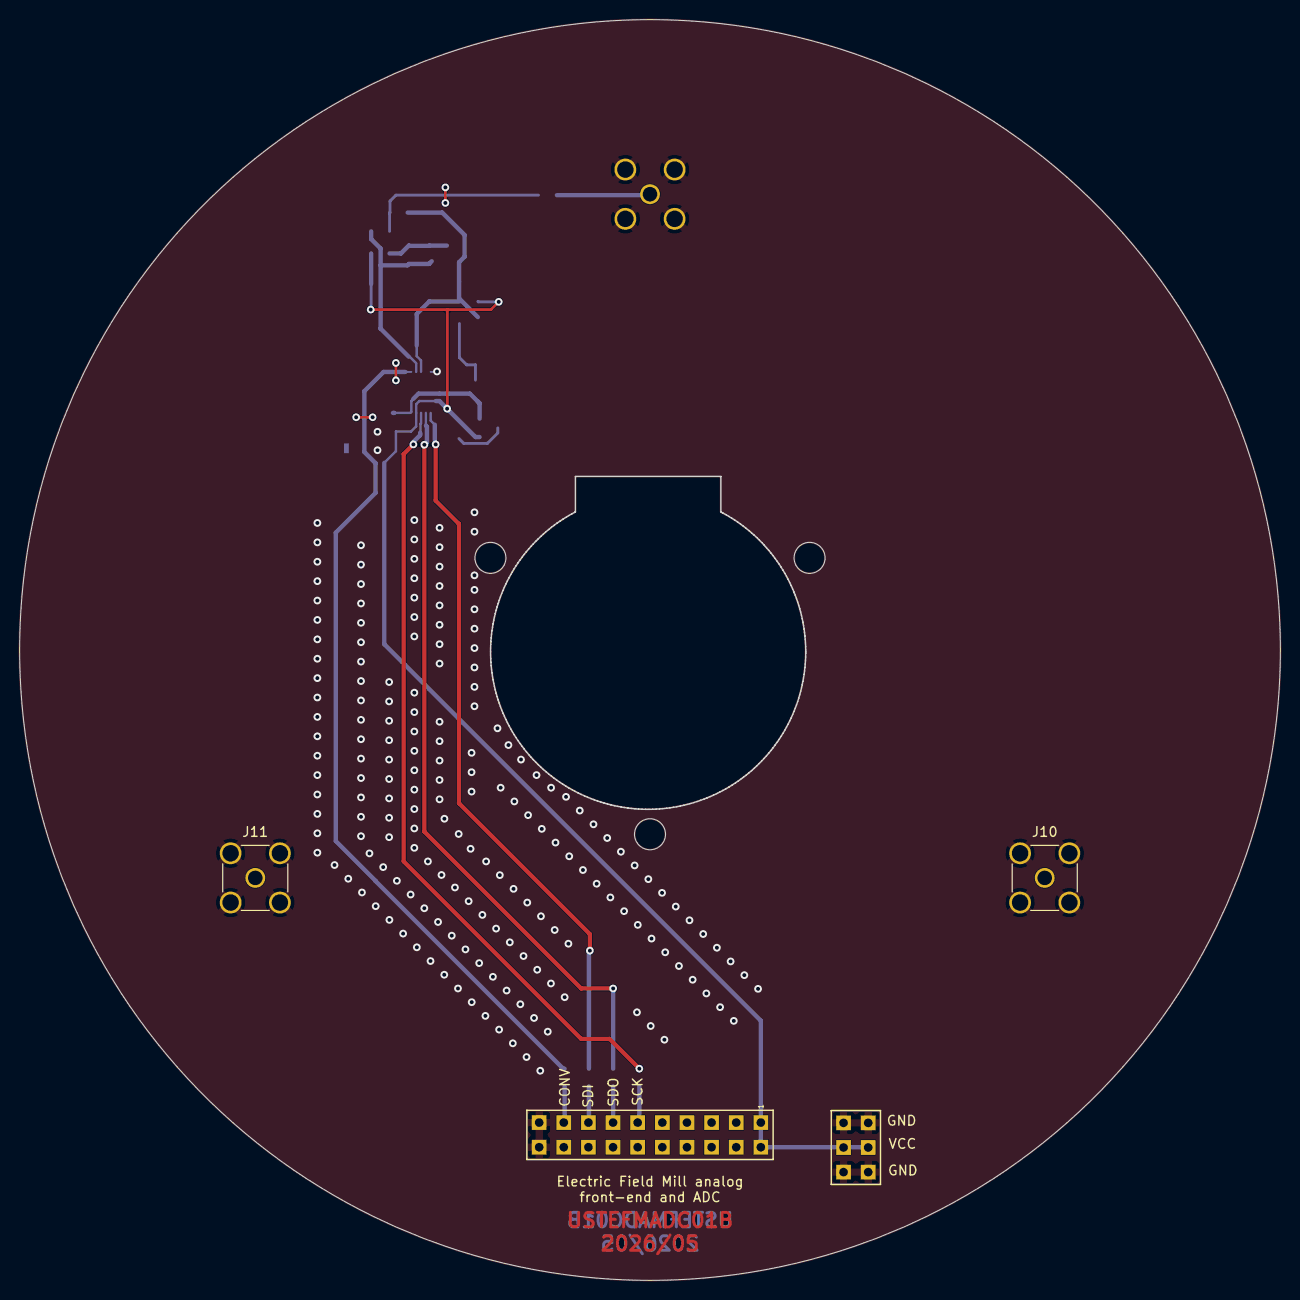
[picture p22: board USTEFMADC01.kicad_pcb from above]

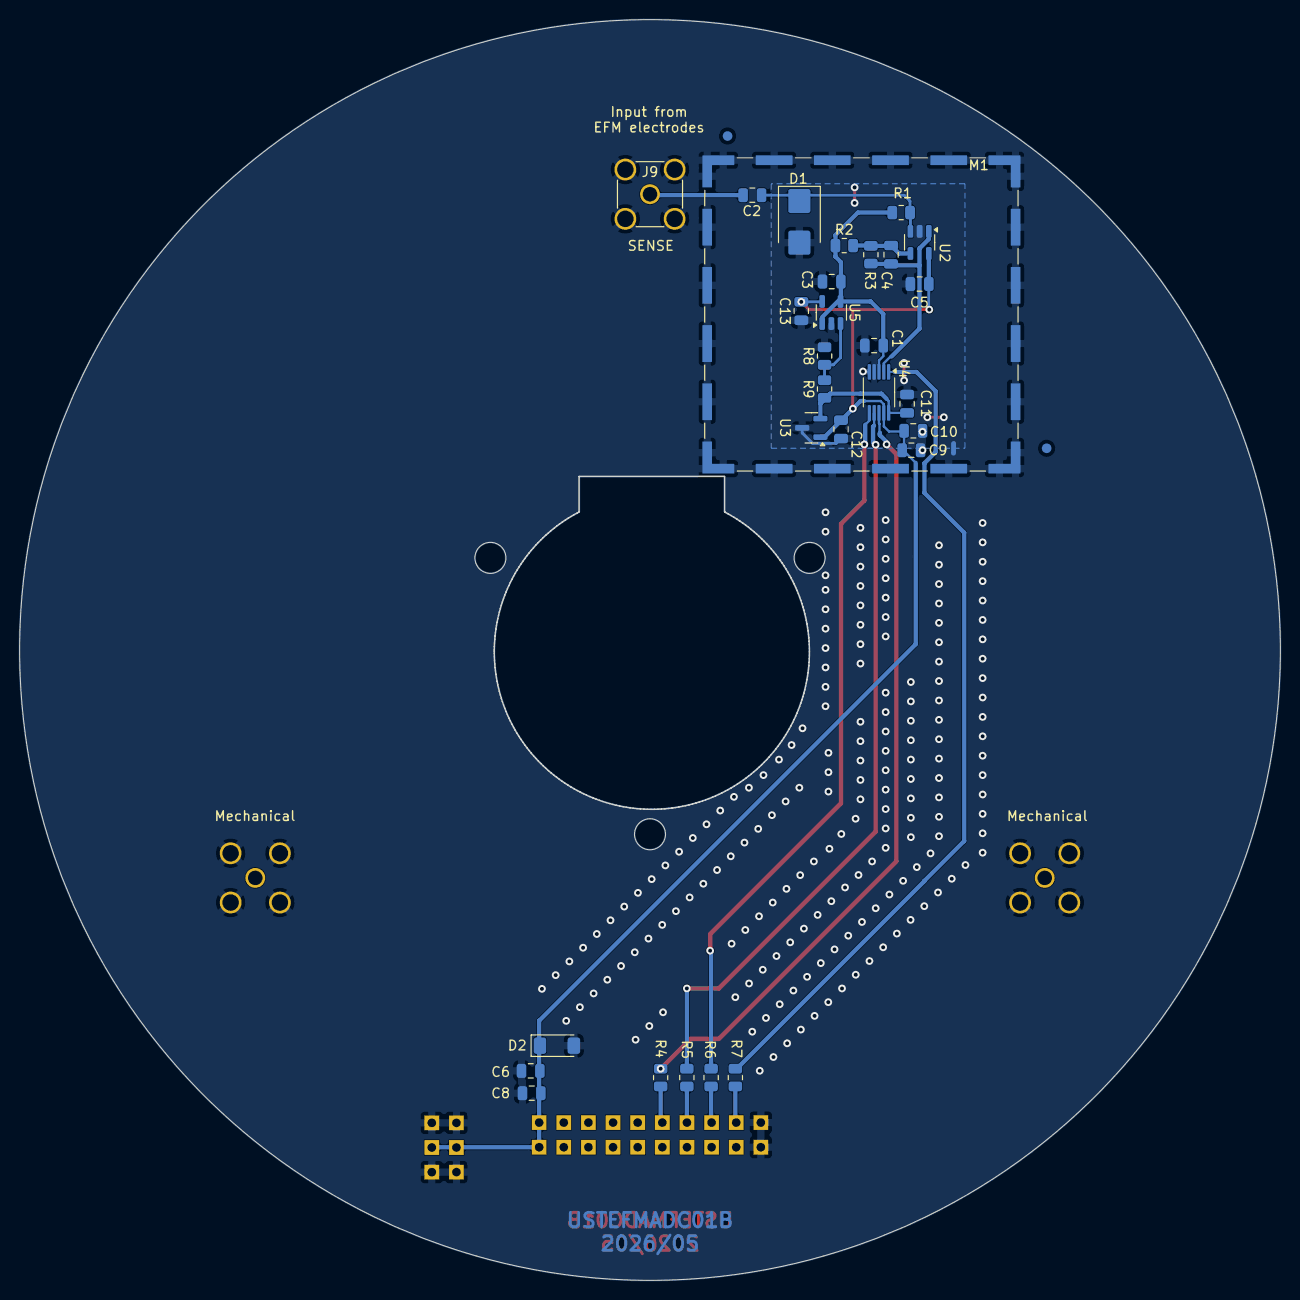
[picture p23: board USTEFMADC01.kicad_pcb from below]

Board: 2 copper layers, 130.0 x 130.0 mm, 36 parts (32 on the bottom side), 18 nets.

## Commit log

2025-05-14 Update to actual state
    [EFMADC01.kicad_pcb, EFMADC01.kicad_sch]
2025-05-14 update layout
    [EFMADC01.kicad_pcb, EFMADC01.kicad_sch]
2025-05-14 rename souurce files
    [USTEFMADC01.kicad_pcb, USTEFMADC01.kicad_sch]
2025-05-14 Update actions products
    [EFMADC01-B_Adhesive.dxf, EFMADC01-B_Courtyard.dxf, EFMADC01-B_Cu.dxf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]
2025-05-14 solve DRC issues
    [USTEFMADC01.kicad_pcb]
2026-06-25 Upadte to version 01B, update actions
    [USTEFMADC01.kicad_pcb, USTEFMADC01.kicad_sch]
2026-06-25 solve issues
    [USTEFMADC01.kicad_pcb]
